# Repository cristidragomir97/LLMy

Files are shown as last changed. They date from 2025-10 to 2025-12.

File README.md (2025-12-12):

# LLMy (leh·mee)
<p>
  
  
  
</p>

<p align="center">
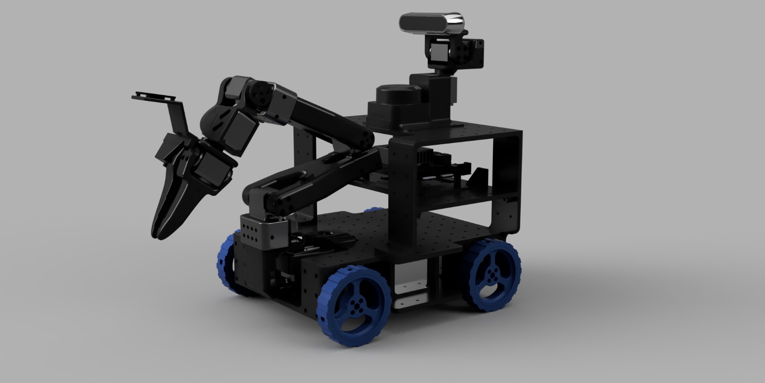
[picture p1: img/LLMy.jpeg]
LLMy Robot
  
</p>

**LLMy** is a fully 3D-printed mobile manipulator designed for **AI experimentation**, **research**, and **education**. Building upon [LeRobot](https://github.com/huggingface/lerobot) and [LeKiwi](https://github.com/SIGRobotics-UIUC), it introduces hardware improvements and comprehensive ROS2 integration.

* 🔧 **Fully 3D Printable** - ORP Grid-based modular design with complete CAD files
* 🤖 **ROS2 Native** - Complete ros2_control integration with MoveIt2 & Nav2 support
* 🎮 **Simulation Ready** - Digital-twin Gazebo simulation with virtual sensors and controllers
* 📷 **RGB-D Vision** - Depth sensing gives you the distance and physical parameters of the objects you detect using neural nets.
* ⚡ **145W Power** - 4-5 hours runtime with USB-C charging
* 💰 **Affordable** - Starting at ~$280 for the base platform

---

## ⚙️ Hardware
The LLMy platform combines a **4-wheel skid-steer base** for robust differential drive mobility with a **6-DOF SO-ARM100 robotic arm** for manipulation tasks. A **pan-tilt elevated camera mount** provides flexible perception capabilities, allowing the robot to survey its environment while performing manipulation operations.

LLMy is designed to be easy to assamble, easy to get started with and easy to expand. 

### Actuators

**12x Feetech STS3215 Servos (12V, 30KG torque):**
- 4x Base wheels (skid-steer drive)
- 6x Arm joints (SO-ARM100)
- 2x Camera head (pan & tilt)

**Control Options:**
- [FE-URT-1](https://www.feetechrc.com/FE-URT1-C001.html)
- [Waveshare Serial Bus Servo Driver](https://www.waveshare.com/bus-servo-adapter-a.htm)

### Power System

- **145W USB-C power bank** with USB-PD trigger modules
- **Hot-swappable charging** - operate while charging
- **4-5 hour runtime** on single charge
- **Nearly solderless** - simplified assembly

### Sensors & Perception

- **RGB-D Camera** - RealSense D435i, ZED 2i, or Orbbec Gemini 2
- **IMU (ICM-20948)** - 9-axis sensor for odometry and SLAM
- **LiDAR (Optional)** - RPLidar C1
- **Wrist Camera** - 640x480 USB camera for manipulation tasks
- **Universal 1/4" mount** - Compatible with various camera systems

### Mechanical Design
- **[ORP Grid-based structure](https://openroboticplatform.com/designrules)** - Modular, expandable design
- **3D printable STL files** - Available in [`/parts`](/parts/) directory
- **Fusion 360 source** - Editable CAD files for customization
- **Expansion ready** - 20x20mm Grid layout supports additional sensors and actuators

### System Diagram

```mermaid
graph TB

    subgraph PowerDelivery["Power Delivery"]
      Battery["145W USB-C Power Bank"]
      Battery --> USBPD1["USB-PD Trigger 1<br/>12V"]
      Battery --> USBPD2["USB-PD Trigger 2<br/>12V"]
    end

    USBPD1 --> SBC["Raspberry Pi 5 / Jetson Orin Nano"]
    USBPD2 --> MotorDriver["Serial Motor Controller<br/>FE-URT-1 / Waveshare"]

    subgraph Actuators["Actuators"]
      MotorDriver -->|Daisy Chain| M1["Servo Motors x11<br/>STS3215"]
    end

    MotorDriver <-->|UART| SBC

    subgraph Sensors["Sensors"]
      IMU["IMU<br/>ICM-20948"]
      Camera["Head Camera<br/>RGB-D"]
      Wrist["Wrist Camera<br/>640x480 USB"]
      LiDAR["LiDAR<br/>RPLidar C1"]
    end

    IMU <-->|I2C| SBC
    Camera -->|USB| SBC
    Wrist -->|USB| SBC
    LiDAR -.->|USB| SBC

```

### Pricing
**📋 [Complete BOM & Sourcing Guide](docs/bom.md)**
| Configuration | US Price | EU Price | What's Included |
|---|---|---|---|
| **Base Platform** | **$264** | **€247** | Servos, controller, IMU, battery |
| **+ RGB-D Camera** | **$498-763** | **€477-696** | + Orbbec Gemini 2/ZED 2i |
| **+ LIDAR** | **$587-852** | **€556-775** | + RPLidar C1/YDLidar options |

---

## 🚀 Quick Start

### 🎮 Simulation (Fastest Way to Try LLMy!)

Get the robot running in Gazebo simulation in just a few commands:

```bash
# Clone and build the workspace
git clone github.com/cristidragomir97/llmy llmy_ws
cd llmy_ws/ros
colcon build
source install/setup.bash

# Launch Gazebo simulation with controllers
ros2 launch llmy_gazebo sim.launch.py
```

The robot will spawn in Gazebo with all controllers active. 

In a new terminal - start Xbox controller teleoperation

```bash
ros2 launch llmy_teleop_xbox teleop_xbox.launch.py
```
**🎮 Xbox Controller Mapping:**
- **🏎️ Base Movement:** Right stick (forward/back + rotate)
- **🦾 Arm Control:**
  - **Joint 1:** RB button (+) / LB button (-)
  - **Joint 2:** RT trigger (+) / LT trigger (-)
  - **Joint 3:** Y button (+) / A button (-)
  - **Joint 4:** B button (+) / X button (-)
  - **Joint 5:** Start button (+) / Back button (-)
  - **Joint 6:** Right stick click (+) / Left stick click (-)
- **📷 Camera Control:**
  - **Pan:** D-pad up/down
  - **Tilt:** D-pad left/right

For detailed setup instructions, hardware configuration, and troubleshooting, see:

**📖 [Getting Started Guide](docs/getting-started.md)** - Complete installation and setup instructions for both simulation and hardware

---

## 🏗️ Architecture

LLMy follows a modular ROS2 architecture that separates concerns between simulation, hardware interfaces, control, and user interaction. 

- **Hardware Abstraction**: The `ros2_control` framework provides a clean interface between high-level controllers (MoveIt2, Nav2) and low-level hardware, allowing the same code to run in both simulation and on real hardware.

- **Modular Sensors**: Each sensor system (cameras, IMU, LIDAR) is encapsulated in its own ROS2 package, publishing standardized messages that any application can consume. This makes it easy to swap sensors or add new ones without modifying application code.

- **Layered Control**: The control stack is separated into layers - from the servo manager handling individual motor commands, through the ros2_control plugin managing the hardware interface, up to high-level motion planning with MoveIt2 and navigation with Nav2.

- **Simulation-First Development**: Gazebo integration allows safe development and testing before deploying to hardware. The same launch files and controllers work in both environments, reducing the simulation-to-reality gap.

```mermaid
graph TB

    LLMyDescription[📦 LLMy_Description]
    API[📡 ROS2]
    Apps[🤖 AI/ML Applications]

    subgraph "Sensors"
        WristCamera[📷 Wrist Camera<br/>UVC 32x32 RGB]
        HeadCamera[📷 Head Camera<br/>RealSense RGB-D]
        IMU[📐 IMU Sensor<br/>ICM20948]
        LIDAR[📏 LIDAR ]
         CameraNode[📦 LLMy_Camera]
        ImuNode[📦 LLMy_IMU]
        LidarNode[📦 rplidar]
    end

    subgraph "Control Layer"
        Control[🎛️ ros2_control Framework]
        LLMyControl[📦 LLMy_Control]
        LLMyControlPlugin[📦 LLMy_ControlPlugin]
    end
    
    subgraph "Actuators"
        LLMyServoManager[📦 LLMy_ServoManager]
        Base[<strong>Skid-Steer Base</strong><br/>4x ST3215 Servos]
        Arm[6-DOF Arm<br/>6x ST3215 Servos]
        Head[Pan & Tilt System<br/>2x ST3215 Servos]
    end

    %% Top to bottom flow
    LLMyDescription --> API

    LIDAR --> LidarNode
    WristCamera --> CameraNode
    HeadCamera --> CameraNode
    IMU --> ImuNode

    LidarNode --> API
    CameraNode --> API
    ImuNode --> API

    API <--> Apps
    API --> Control

    LLMyControl --> Control
    Control --> LLMyControlPlugin
    LLMyControlPlugin --> LLMyServoManager

    LLMyServoManager --> Base
    LLMyServoManager --> Arm
    LLMyServoManager --> Head
    
```

--- 

### 📦 ROS Packages

**Core Packages:**
- [**llmy_description**](ros/src/llmy_description/) - Robot URDF model with accurate kinematics and collision meshes
- [**llmy_control_plugin**](ros/src/llmy_control_plugin) - ros2_control hardware bridge enabling MoveIt2/Nav2 integration
- [**llmy_control**]() - Controller parameters and ros2_control configurations
- [**llmy_servo_manager**]() - Low-level motor control with real-time telemetry
- [**llmy_teleop_xbox**]() - Xbox controller interface for manual operation

**Sensor & Vision:**
- [**llmy_camera**]() - RGB-D camera integration with depth-to-laser conversion
- [**llmy_imu**]() - IMU sensor fusion for orientation and navigation

**Simulation Packages**
- **llmy_gazebo** - Configurations and launch files for the Gazebo Classic

**📋 [Detailed Package Documentation](docs/packages.md)**

--- 
## 🙏 Credits & Acknowledgments
This project stands on the shoulders of incredible open-source work:

- **[LeRobot Team](https://github.com/huggingface/lerobot)** - For pioneering accessible robotics and AI integration
- **[SIGRobotics-UIUC](https://github.com/SIGRobotics-UIUC)** - For their foundational work on LeKiwi
- **[Pavan Vishwanath](https://github.com/Pavankv92)** - ROS2 package development for [LeRobot SO-ARM101](https://github.com/Pavankv92/lerobot_ws)
- **[Mateus Menezes](https://github.com/mateusmenezes95)** - [Omnidirectional controllers](https://github.com/mateusmenezes95/omnidirectional_controllers) and [AxeBot](https://github.com/mateusmenezes95/axebot) simulation expertise
- **[Gaotian Wang](https://github.com/Vector-Wangel/XLeRobot)** - For his amazing work on XLeRobot. Also for being kind enough to publish the STEP files for his robot upon request, files that were used to create the camera tower for LLMy. 

---
<div align="center">

<strong>⭐ Star this repo if LLMy helped you build something awesome! ⭐</strong>
</div>

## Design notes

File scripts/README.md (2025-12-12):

# LLMy Setup Scripts

Utility scripts for configuring and calibrating your LLMy robot.

## Scripts Overview

### 1. `set_servo_id.py` - Servo ID Configuration

Interactive tool for setting FEETECH STS3215 servo IDs one by one.

**Usage:**

```bash
# List all servos on the bus with telemetry
python3 set_servo_id.py --list

# Interactive mode - configure servos one by one
python3 set_servo_id.py

# Direct ID change
python3 set_servo_id.py --old-id 1 --new-id 5

# Custom serial port
python3 set_servo_id.py --port /dev/ttyACM0 --list
```

**LLMy ID Assignments:**
- Base (locomotion): IDs **1, 2, 3**
- Arm (manipulator): IDs **4, 5, 6, 7, 8, 9**
- Head (pan & tilt): IDs **10, 11**

**Workflow:**
1. Connect servos **one at a time** to avoid ID conflicts
2. Run interactive mode: `python3 set_servo_id.py`
3. For each servo:
   - Connect it to the bus
   - Script detects current ID
   - Enter desired new ID
   - Disconnect and connect next servo
4. Final verification scan shows all configured servos

---

### 2. `calibrate_arm.py` - Arm Calibration

Calibrates arm joint zero positions and movement limits.

**Usage:**

```bash
# Basic calibration (will prompt for save)
python3 calibrate_arm.py

# Auto-save to config file
python3 calibrate_arm.py --config ~/llmy_ws/ros/src/llmy_servo_manager/config/servo_manager.yaml

# Custom serial port
python3 calibrate_arm.py --port /dev/ttyUSB0
```

**⚠️ IMPORTANT:** Stop all ROS2 nodes before running calibration!

```bash
# Kill any running servo manager nodes
pkill -f servo_manager
```

**Calibration Process:**

1. **Zero Position Setup:**
   - Position arm fully erect (vertical)
   - Close gripper completely
   - Center wrist rotation
   - Script records zero positions

2. **Joint Limit Calibration:**
   - For each of 6 arm joints:
     - Move joint to minimum position → record
     - Move joint to maximum position → record
   - Script validates and saves limits

3. **Verification:**
   - Arm returns to zero position
   - Summary table shows all calibration data
   - Option to save to YAML config

**Output Example:**
```
┌─────────────────────────┬──────┬──────────┬─────────┬─────────┐
│ Joint                   │  ID  │ Zero Pos │ Min Pos │ Max Pos │
├─────────────────────────┼──────┼──────────┼─────────┼─────────┤
│ Joint 1 (Base Rotation) │   4  │  2048    │   512   │  3584   │
│ Joint 2 (Shoulder)      │   5  │  2048    │   768   │  3328   │
...
```

**What Gets Saved:**

The calibration tool updates `servo_manager.yaml` with:
- `arm_zero_positions`: Reference position for each joint (6 values)
- `arm_min_limits`: Minimum safe position in ticks (6 values)
- `arm_max_limits`: Maximum safe position in ticks (6 values)

These limits are automatically enforced by the servo manager to prevent damage.

---

## Prerequisites

### Hardware Setup
- Robot powered on (12V to servos)
- Serial connection established (USB or UART)
- Correct serial port identified

### Software Requirements
```bash
# Install st3215 Python library
pip install st3215

# Install PyYAML for config management
pip install pyyaml
```

### Permissions
```bash
# Add your user to dialout group for serial access
sudo usermod -a -G dialout $USER
# Log out and back in for changes to take effect
```

---

## Common Serial Ports

| Platform | Port | Description |
|---|---|---|
| Raspberry Pi | `/dev/ttyUSB0` | USB adapter |
| Jetson Nano/Orin | `/dev/ttyTHS1` | Hardware UART |
| Generic Linux | `/dev/ttyACM0` | USB CDC adapter |
| Waveshare adapter | `/dev/ttyUSB0` | FT232 USB-Serial |

**Find your port:**
```bash
# List all serial devices
ls /dev/tty{USB,ACM,THS}* 2>/dev/null

# Monitor kernel messages when plugging in
dmesg | tail
```

---

## Workflow: Full Robot Setup

**Complete setup from scratch:**

```bash
# 1. Set all servo IDs (connect one at a time)
cd ~/llmy_ws/scripts
python3 set_servo_id.py

# 2. Verify all servos are detected
python3 set_servo_id.py --list

# 3. Calibrate arm joints
python3 calibrate_arm.py --config ../ros/src/llmy_servo_manager/config/servo_manager.yaml

# 4. Build and launch ROS workspace
cd ~/llmy_ws/ros
colcon build
source install/setup.bash
ros2 launch llmy_bringup bringup_robot.launch.py
```

---

## Troubleshooting

### Script can't connect to servos
```bash
# Check port exists
ls -l /dev/ttyUSB0

# Check permissions
groups  # Should show 'dialout'

# Try different baud rates
python3 set_servo_id.py --baud 115200
```

### Servo not responding during calibration
- Ensure 12V power supply is connected
- Check servo cables are properly seated
- Verify servo ID matches expected value
- Try power cycling the servo

### Calibration data not saving
- Verify config file path is correct
- Check file permissions (must be writable)
- Review backup file (.backup) for changes
- Manually inspect YAML syntax

### ROS node conflicts
```bash
# Kill all servo-related processes
pkill -f servo_manager
pkill -f llmy

# Verify no nodes running
ros2 node list
```

---

## Advanced Usage

### Batch ID Configuration
```bash
# Script for setting multiple servos
for id in {1..11}; do
  echo "Connect servo for ID $id and press enter..."
  read
  python3 set_servo_id.py --old-id 1 --new-id $id
done
```

### Custom Calibration Workflow
```python
# Manual calibration via Python API
from st3215 import ST3215

servo = ST3215('/dev/ttyUSB0')
pos = servo.ReadPosition(4)  # Read joint 1 position
print(f"Current position: {pos} ticks")
```

### Verify Limits Are Enforced
```bash
# After calibration, test limit enforcement
ros2 topic pub /motor_manager/arm_cmd std_msgs/msg/Float64MultiArray "data: [10.0, 0, 0, 0, 0, 0]"
# Joint should clamp to max limit, not attempt invalid position
```

---

## Support

For issues or questions:
- GitHub Issues: https://github.com/cristidragomir97/llmy/issues
- Documentation: [docs/getting-started.md](../docs/getting-started.md)

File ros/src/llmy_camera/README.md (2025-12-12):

# llmy_camera

Camera integration package for the LLMy robot, providing both a head-mounted RealSense RGB-D camera and a wrist-mounted USB camera with compressed image transport and laser scan conversion capabilities.

## Overview

The llmy_camera package manages two camera systems:
- **Head Camera**: Intel RealSense RGB-D camera (D435i, D455, etc.) mounted on the pan/tilt head
- **Wrist Camera**: USB camera (640x480) mounted on the end-effector for close-up manipulation tasks

## Launch Files

### `camera.launch.py`

Main launch file that brings up both camera systems with full feature set:

**Components:**
- RealSense RGB-D camera (head_camera namespace)
- USB wrist camera (wrist_camera namespace)
- Compressed image transport for both cameras
- Depth-to-laser-scan conversion for navigation

```bash
# Launch both cameras with all features
ros2 launch llmy_camera camera.launch.py

# Launch without wrist camera
ros2 launch llmy_camera camera.launch.py enable_wrist_camera:=false

# Launch without laser scan conversion
ros2 launch llmy_camera camera.launch.py enable_laser_scan:=false

# Disable compressed transport
ros2 launch llmy_camera camera.launch.py enable_compressed:=false
```

### `realsense_only.launch.py`

Minimal launch file for RealSense camera only (no wrist camera, no laser scan, no compression):

```bash
# Launch only RealSense camera
ros2 launch llmy_camera realsense_only.launch.py

# Specify device type
ros2 launch llmy_camera realsense_only.launch.py device_type:=d435i
```

## Launch Arguments

### `camera.launch.py` Arguments

| Argument | Default | Description |
|---|---|---|
| `camera_name` | `head_camera` | RealSense camera name |
| `device_type` | `` | RealSense device type (auto-detect if empty) |
| `enable_wrist_camera` | `true` | Enable USB wrist camera |
| `wrist_camera_device` | `/dev/video0` | Video device path for wrist camera |
| `enable_compressed` | `true` | Enable compressed image transport |
| `enable_laser_scan` | `true` | Enable depth to laser scan conversion |
| `laser_scan_min_height` | `-0.5` | Minimum height for laser scan slice (m) |
| `laser_scan_max_height` | `0.5` | Maximum height for laser scan slice (m) |
| `laser_scan_angle_min` | `-1.57` | Minimum scan angle (-90°) |
| `laser_scan_angle_max` | `1.57` | Maximum scan angle (+90°) |
| `laser_scan_angle_increment` | `0.005` | Angular resolution |
| `laser_scan_range_min` | `0.2` | Minimum range (m) |
| `laser_scan_range_max` | `10.0` | Maximum range (m) |

### `realsense_only.launch.py` Arguments

| Argument | Default | Description |
|---|---|---|
| `camera_name` | `camera` | RealSense camera name |
| `device_type` | `d435i` | RealSense device type |

## Topics Published

### Head Camera (RealSense)

**Color Stream:**
- `/head_camera/head_camera/color/image_raw` - Raw color image (640x480@30Hz)
- `/head_camera/head_camera/color/image_compressed` - Compressed color image (JPEG)
- `/head_camera/head_camera/color/camera_info` - Camera calibration

**Depth Stream:**
- `/head_camera/head_camera/depth/image_rect_raw` - Rectified depth image
- `/head_camera/head_camera/depth/camera_info` - Depth camera calibration

**Laser Scan:**
- `/scan` - 2D laser scan converted from depth (for navigation)

### Wrist Camera (USB)

- `/wrist_camera/image_raw` - Raw wrist camera image (640x480@30Hz)
- `/wrist_camera/image_compressed` - Compressed wrist image (JPEG)
- `/wrist_camera/camera_info` - Camera calibration

## Supported Hardware

### RealSense Cameras
- Intel RealSense D435i (recommended)
- Intel RealSense D455
- Intel RealSense L515
- Other RealSense RGB-D cameras

### Wrist Camera
- Any UVC-compatible USB camera
- Default: 640x480@30fps, MJPEG format

## Usage Examples

### View Camera Streams

```bash
# View head camera color stream
ros2 run rqt_image_view rqt_image_view /head_camera/head_camera/color/image_raw

# View head camera depth
ros2 run rqt_image_view rqt_image_view /head_camera/head_camera/depth/image_rect_raw

# View wrist camera
ros2 run rqt_image_view rqt_image_view /wrist_camera/image_raw

# View compressed images (bandwidth efficient)
ros2 run rqt_image_view rqt_image_view /head_camera/head_camera/color/image_compressed/compressed
ros2 run rqt_image_view rqt_image_view /wrist_camera/image_compressed/compressed
```

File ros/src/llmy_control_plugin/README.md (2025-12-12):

# llmy_control_plugin

A `ros2_control` **SystemInterface** hardware plugin that bridges ros2_control to the LLMy servo manager via ROS2 topics.

## Purpose

This plugin implements the hardware abstraction layer for ros2_control, allowing standard controllers to work with LLMy hardware. It uses a topic-based interface rather than direct serial communication, which decouples the control stack from hardware details.

## Topic Interface

### Published (Commands to Hardware)

- **`/motor_manager/base_cmd`** - `std_msgs/Float64MultiArray`
  - `[back_motor_rotation, left_motor_rotation, right_motor_rotation]` (rad/s)
  - QoS: Best-effort, depth 1

- **`/motor_manager/arm_cmd`** - `std_msgs/Float64MultiArray`
  - `[joint_1, joint_2, joint_3, joint_4, joint_5, joint_6]` (radians)
  - QoS: Best-effort, depth 1

- **`/motor_manager/head_cmd`** - `std_msgs/Float64MultiArray`
  - `[camera_pan, camera_tilt]` (radians)
  - QoS: Best-effort, depth 1

### Subscribed (Feedback from Hardware)

- **`/motor_manager/joint_states`** - `sensor_msgs/JointState`
  - All joint positions and velocities
  - QoS: Reliable, depth 5

## Hardware Interfaces Exported

The plugin exports these command and state interfaces to ros2_control:

**Base (velocity interfaces):**
- `back_motor_rotation/velocity`
- `left_motor_rotation/velocity`
- `right_motor_rotation/velocity`

**Arm (position interfaces):**
- `1/position`, `2/position`, `3/position`, `4/position`, `5/position`, `6/position`

**Head (position interfaces):**
- `camera_pan/position`, `camera_tilt/position`

## Configuration

### Hardware Interface Config

Configuration is in `llmy_control/config/ros2_control_bridge.yaml`:

```yaml
hardware_interface:
  plugin: "llmy_control_plugin/ROS2ControlBridge"
  base_joints: [back_motor_rotation, left_motor_rotation, right_motor_rotation]
  arm_joints: ["1", "2", "3", "4", "5", "6"]
  head_joints: [camera_pan, camera_tilt]
```

## Usage

This plugin is loaded automatically by `llmy_control/control_stack.launch.py`. You don't typically interact with it directly.

### Normal Usage

```bash
# Launch complete system (includes this plugin)
ros2 launch llmy_control control_stack.launch.py
```

### Standalone Testing

```bash
# 1. Start servo manager
ros2 launch llmy_servo_manager servo_manager.launch.py

# 2. Launch plugin (requires robot_description)
ros2 launch llmy_control_plugin bringup.launch.py
```

## Implementation Notes

### Lifecycle

1. **`on_init()`** - Read configuration, register joint interfaces
2. **`on_configure()`** - Create publishers and subscribers
3. **`on_activate()`** - Ready for control
4. **`read()`** - Update state interfaces from `/motor_manager/joint_states` (called at update rate)
5. **`write()`** - Publish commands from command interfaces (called at update rate)

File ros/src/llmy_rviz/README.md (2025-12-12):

# llmy_rviz

RViz2 configuration and visualization package for the LLMy robot.

## Features

This package provides comprehensive visualization for:

### Robot Visualization
- **Robot Model**: Full 3D visualization of the LLMy robot from URDF
- **TF Tree**: Transform frame visualization showing all coordinate frames

### Sensor Data
- **LaserScan**: 2D lidar visualization (`/scan` topic)
- **Head Camera RGB**: Color camera feed from head camera
- **Head Camera Depth**: Depth camera visualization (disabled by default)
- **Wrist Camera**: RGB camera on robot wrist (disabled by default)
- **Depth PointCloud**: 3D point cloud from depth camera (disabled by default)

### SLAM & Navigation
- **Map**: Occupancy grid map from SLAM (`/map` topic)
- **Global Plan**: Planned path from navigation (`/plan` topic)
- **Local Plan**: Local planner trajectory (`/local_plan` topic)
- **Local Costmap**: Real-time obstacle avoidance costmap
- **Global Costmap**: Global planning costmap

### Tools
- **2D Pose Estimate**: Set initial robot pose for localization
- **2D Nav Goal**: Send navigation goals to the robot
- **Measure**: Measure distances in the environment
- **Publish Point**: Click to publish 3D points

## Usage

### Launch RViz with default configuration:
```bash
ros2 launch llmy_rviz rviz.launch.py
```

### Launch with custom config:
```bash
ros2 launch llmy_rviz rviz.launch.py rviz_config:=/path/to/config.rviz
```

### Launch with hardware (no sim time):
```bash
ros2 launch llmy_rviz rviz.launch.py use_sim_time:=false
```

## Configuration

The main RViz configuration file is located at:
```
rviz/llmy.rviz
```

You can customize this file or create new configurations and save them in the `rviz/` directory.

## Topics Subscribed

- `/robot_description` - Robot model URDF
- `/scan` - LaserScan data
- `/map` - Occupancy grid map
- `/plan` - Global navigation plan
- `/local_plan` - Local navigation plan
- `/local_costmap/costmap` - Local costmap
- `/global_costmap/costmap` - Global costmap
- `/head_camera/rgb` - Head camera RGB image
- `/head_camera/depth` - Head camera depth image
- `/head_camera/depth/points` - Depth point cloud
- `/wrist_camera/rgb` - Wrist camera RGB image

## Dependencies

- rviz2
- rviz_common
- rviz_default_plugins
- robot_state_publisher
- llmy_description

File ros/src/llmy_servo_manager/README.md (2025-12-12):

# LLMy Servo Manager

Servo control system for the LLMy Robot.

- **Multi-Motor Support**: Controls locomotion, arm, and head motor groups independently
- **Real-time Telemetry**: Publishes motor states at configurable rates
- **Robust Error Handling**: Comprehensive connectivity testing and graceful error recovery

## Architecture

### Core Modules

- **`servo_manager_node.py`**: Main ROS2 node orchestrating all components
- **`config.py`**: Configuration management and parameter validation
- **`motor_manager.py`**: Low-level motor communication and control
- **`brake_system.py`**: Safe motor braking with multiple strategies
- **`command_handlers.py`**: ROS message processing and motor command conversion
- **`telemetry.py`**: Motor state publishing and monitoring

## Configuration

The servo manager is configured via ROS2 parameters, typically loaded from `config/servo_manager.yaml`:

### Communication Parameters
```yaml
port: "/dev/ttyTHS1"          # Serial port for motor communication
baud: 1000000                 # Baud rate (default: 1 Mbps)
ticks_per_rev: 4096           # Encoder ticks per revolution
telemetry_rate: 30.0          # Telemetry publishing rate (Hz)
```

### Motor Group Configuration
```yaml
# Enable/disable motor groups
loc_enable: true              # Locomotion motors
arm_enable: true              # Arm motors  
head_enable: true             # Head motors

# Motor IDs for each group
loc_ids: [1, 2, 3]           # Locomotion motor IDs
arm_ids: [4, 5, 6, 7, 8, 9]  # Arm motor IDs
head_ids: [10, 11]           # Head motor IDs

# Acceleration settings (per motor)
loc_accel: [15, 15, 15]
arm_accel: [20, 20, 15, 15, 25, 25]
head_accel: [15, 15]

# Speed scaling factors (0.0 to 2.0)
loc_speed_scale: 0.2         # Conservative for locomotion
arm_speed_scale: 1.0         # Normal for arm
head_speed_scale: 1.0        # Normal for head
```

### Braking System Configuration
```yaml
# Braking method: "torque_disable", "velocity_ramp", "position_brake"
brake_method: "torque_disable"  # Gentlest method (recommended)
velocity_ramp_time: 0.5         # Ramp down time for velocity_ramp (seconds)
brake_acceleration: 100         # Acceleration for position_brake method
```

## ROS2 Interface

### Subscribed Topics

- **`/motor_manager/base_cmd`** (`Float64MultiArray`)
  - Velocity commands for locomotion motors (rad/s)
  - Array size must match number of locomotion motors

- **`/motor_manager/arm_cmd`** (`Float64MultiArray`)  
  - Position commands for arm motors (radians)
  - Array size must match number of arm motors

- **`/motor_manager/head_cmd`** (`Float64MultiArray`)
  - Position commands for head motors (radians)
  - Array size must match number of head motors

### Published Topics

- **`/motor_manager/joint_states`** (`JointState`)
  - Current motor positions and velocities
  - Published at configured telemetry rate
  - Contains all enabled motors with naming: `motor_{id}`

## Usage

### Basic Launch
```bash
ros2 launch llmy_servo_manager servo_manager.launch.py
```

### With Custom Configuration
```bash
ros2 launch llmy_servo_manager servo_manager.launch.py \
    config_file:=custom_servo_config.yaml
```

## Monitoring and Diagnostics

### View Motor States
```bash
ros2 topic echo /motor_manager/joint_states
```

### Check Node Status
```bash
ros2 node info /servo_manager_node
```

### Monitor Motor Connectivity
The node automatically tests motor connectivity on startup and logs detailed status information.

## Troubleshooting

### Common Issues

1. **Serial Port Permission Denied**
   ```bash
   sudo usermod -a -G dialout $USER
   # Then logout and login again
   ```

2. **Motors Not Responding**
   - Check physical connections
   - Verify motor IDs in configuration
   - Ensure proper power supply
   - Check serial port settings

### Debug Mode
Enable debug logging to see detailed brake operations:
```bash
ros2 run llmy_servo_manager servo_manager_node --ros-args --log-level DEBUG
```

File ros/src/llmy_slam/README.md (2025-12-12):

# llmy_slam

SLAM (Simultaneous Localization and Mapping) integration for the LLMy robot using [slam_toolbox](https://github.com/SteveMacenski/slam_toolbox).

This package provides custom launch files and configurations specifically tailored for the LLMy robot's hardware setup.

## Overview

This package wraps slam_toolbox with LLMy-specific configurations for:
- **Sensor input**: RPLidar on `/scan` topic
- **Odometry**: Omnidirectional controller publishing `/omnidirectional_controller/odom` and TF `odom` → `base_link`
- **Base frame**: `base_link`
- **Map frame**: `map`

## Prerequisites

1. **Install slam_toolbox**:
   ```bash
   sudo apt install ros-${ROS_DISTRO}-slam-toolbox
   ```

2. **Ensure RPLidar is publishing** on `/scan` topic:
   - Enable RPLidar in your bringup configuration
   - Or use depth-to-laserscan from the RealSense camera

3. **Verify odometry is being published**:
   ```bash
   ros2 topic echo /omnidirectional_controller/odom
   ```

   Note: slam_toolbox uses TF transforms (`odom` → `base_link`) rather than subscribing to the odometry topic directly.

## Usage

### 1. Mapping Mode (Creating a Map)

Launch slam_toolbox in online asynchronous mapping mode:

```bash
ros2 launch llmy_slam online_async_launch.py
```

**Options:**
- `use_sim_time:=true` - Use simulation time (for Gazebo)
- `params_file:=/path/to/custom/params.yaml` - Use custom parameters

**While mapping:**
- Drive the robot around using teleop or xbox controller
- The map will be built in real-time
- You can view the map in RViz by adding the `/map` topic

**To save the map:**

Use the slam_toolbox service:
```bash
ros2 service call /slam_toolbox/save_map slam_toolbox/srv/SaveMap "{name: {data: '/path/to/your/map_name'}}"
```

This will create two files:
- `map_name.posegraph` - SLAM graph data
- `map_name.data` - Serialized map data

### 2. Localization Mode (Using a Pre-built Map)

Once you have a saved map, you can use it for localization only:

1. **Update the map path** in `config/mapper_params_localization.yaml`:
   ```yaml
   map_file_name: /path/to/your/saved/map_name
   ```

2. **Launch localization**:
   ```bash
   ros2 launch llmy_slam localization_launch.py
   ```

In this mode, the robot will localize itself within the existing map without modifying it.

### 3. Lifelong Mode (Dynamic Mode Switching) ⭐ **Recommended**

Lifelong mode is the most flexible approach, allowing you to **dynamically switch between mapping and localization** using ROS services without restarting the node.

**Launch lifelong mode:**
```bash
ros2 launch llmy_slam lifelong_launch.py
```

**Options:**
- `use_sim_time:=true` - Use simulation time (for Gazebo)
- `params_file:=/path/to/custom/params.yaml` - Use custom parameters

#### Dynamic Mode Switching with Services

Once running, you can control the SLAM behavior using these services:

**1. Pause Mapping (Switch to Localization Mode):**
```bash
ros2 service call /slam_toolbox/pause_new_measurements std_srvs/srv/SetBool "{data: true}"
```

**2. Resume Mapping:**
```bash
ros2 service call /slam_toolbox/pause_new_measurements std_srvs/srv/SetBool "{data: false}"
```

**3. Save the Current Map (while running):**
```bash
ros2 service call /slam_toolbox/serialize_map slam_toolbox/srv/SerializePoseGraph "{filename: '/path/to/map_name'}"
```

**4. Load an Existing Map (while running):**
```bash
ros2 service call /slam_toolbox/deserialize_map slam_toolbox/srv/DeserializePoseGraph "{filename: '/path/to/map_name', match_type: 2}"
```
- `match_type: 1` - Start at the origin of the loaded map
- `match_type: 2` - Start at the current position (relocalize in the map)

**5. Clear the Current Queue:**
```bash
ros2 service call /slam_toolbox/clear_queue std_srvs/srv/Empty
```

#### Example Workflow with Lifelong Mode

```bash
# 1. Launch lifelong SLAM
ros2 launch llmy_slam lifelong_launch.py

# 2. Drive around and build a map
# ... (use teleop/xbox controller)

# 3. Save the map
ros2 service call /slam_toolbox/serialize_map slam_toolbox/srv/SerializePoseGraph \
  "{filename: '/home/user/maps/office_map'}"

# 4. Switch to localization mode (pause mapping)
ros2 service call /slam_toolbox/pause_new_measurements std_srvs/srv/SetBool "{data: true}"

# 5. Later, resume mapping to update the map
ros2 service call /slam_toolbox/pause_new_measurements std_srvs/srv/SetBool "{data: false}"

# 6. Or load a different map entirely
ros2 service call /slam_toolbox/deserialize_map slam_toolbox/srv/DeserializePoseGraph \
  "{filename: '/home/user/maps/warehouse_map', match_type: 2}"
```

#### Advantages of Lifelong Mode

- **No restarts needed** - Switch modes on the fly
- **Flexible workflows** - Map, localize, then continue mapping
- **Multi-session mapping** - Save and continue mapping across multiple sessions
- **Hot-swapping maps** - Load different maps without stopping the node

## Configuration Files

### `config/mapper_params_lifelong.yaml`
Configuration for lifelong mode with dynamic behavior:
- Supports both mapping and localization
- Can load existing maps and continue mapping
- Full service interface for dynamic control
- Recommended for production deployments

### `config/mapper_params_online_async.yaml`
Configuration for online mapping mode. Key parameters:
- `scan_topic: /scan` - Laser scan input
- `odom_frame: odom` - Odometry frame
- `base_frame: base_link` - Robot base frame
- `map_frame: map` - Map frame
- `max_laser_range: 12.0` - RPLidar typical max range
- `resolution: 0.05` - Map resolution (5cm per pixel)
- `minimum_travel_distance: 0.2` - Minimum movement before updating (meters)

### `config/mapper_params_localization.yaml`
Configuration for localization mode. Similar to mapping mode but with:
- `mode: localization` - Only localizes, doesn't update map
- `map_file_name: /path/to/map` - Path to pre-built map

## RViz Visualization

To visualize SLAM in RViz:

1. Launch RViz:
   ```bash
   rviz2
   ```

2. Add the following displays:
   - **TF** - To see coordinate frames
   - **Map** - Topic: `/map`
   - **LaserScan** - Topic: `/scan`
   - **RobotModel** - Uses the URDF description

3. Set **Fixed Frame** to `map`

## Integration with LLMy Bringup

To automatically start SLAM with your robot, you can include this launch file in `llmy_bringup`:

```python
from launch.actions import IncludeLaunchArgument, IncludeLaunchDescription
from launch.launch_description_sources import PythonLaunchDescriptionSource
from launch.substitutions import LaunchConfiguration

# Option 1: Lifelong mode (recommended for flexibility)
slam_launch = IncludeLaunchDescription(
    PythonLaunchDescriptionSource(
        PathJoinSubstitution([
            FindPackageShare('llmy_slam'),
            'launch',
            'lifelong_launch.py'
        ])
    )
)

# Option 2: Online mapping mode (simpler, mapping only)
# slam_launch = IncludeLaunchDescription(
#     PythonLaunchDescriptionSource(
#         PathJoinSubstitution([
#             FindPackageShare('llmy_slam'),
#             'launch',
#             'online_async_launch.py'
#         ])
#     )
# )
```

## Topics

### Subscribed:
- `/scan` (sensor_msgs/LaserScan) - Laser scan from RPLidar
- `/tf` - Transform tree (requires `odom` → `base_link` transform)
- `/tf_static` - Static transforms

**Note**: slam_toolbox does not subscribe to `/omnidirectional_controller/odom` directly. It uses the TF transform `odom` → `base_link` published by the omnidirectional controller.

### Published:
- `/map` (nav_msgs/OccupancyGrid) - Generated map
- `/tf` - Publishes `map` → `odom` transform

## Services

slam_toolbox provides many useful services:

### Core Services

- `/slam_toolbox/pause_new_measurements` - **Pause/resume mapping** (switch to localization mode)
- `/slam_toolbox/serialize_map` - **Save map to file** (posegraph format)
- `/slam_toolbox/deserialize_map` - **Load map from file** and optionally relocalize
- `/slam_toolbox/save_map` - Save map as standard ROS map format (.pgm + .yaml)
- `/slam_toolbox/clear_queue` - Clear the scan queue

### Additional Services

- `/slam_toolbox/toggle_interactive_mode` - Enable/disable interactive markers in RViz
- `/slam_toolbox/clear` - Clear the current graph (start fresh)
- `/slam_toolbox/dynamic_map` - Get the current map
- `/slam_toolbox/manual_loop_closure` - Manually trigger loop closure

List all available services:
```bash
ros2 service list | grep slam_toolbox
```

Get service details:
```bash
ros2 service type /slam_toolbox/pause_new_measurements
ros2 interface show std_srvs/srv/SetBool
```

### Quick Service Reference

**Save map (posegraph format, can be loaded back):**
```bash
ros2 service call /slam_toolbox/serialize_map slam_toolbox/srv/SerializePoseGraph \
  "{filename: '/home/user/maps/my_map'}"
```

**Save map (standard ROS format, for navigation stack):**
```bash
ros2 service call /slam_toolbox/save_map slam_toolbox/srv/SaveMap \
  "{name: {data: '/home/user/maps/my_map'}}"
```

**Load map and relocalize:**
```bash
ros2 service call /slam_toolbox/deserialize_map slam_toolbox/srv/DeserializePoseGraph \
  "{filename: '/home/user/maps/my_map', match_type: 2}"
```

**Pause mapping (localization only):**
```bash
ros2 service call /slam_toolbox/pause_new_measurements std_srvs/srv/SetBool "{data: true}"
```

**Resume mapping:**
```bash
ros2 service call /slam_toolbox/pause_new_measurements std_srvs/srv/SetBool "{data: false}"
```

### Helper Script

For convenience, a helper script is provided to simplify common operations:

```bash
# After building the package, the script will be available at:
ros2 pkg prefix llmy_slam
# Or use it directly from source:
./ros/src/llmy_slam/scripts/slam_control.sh

# Usage examples:
./scripts/slam_control.sh pause                         # Pause mapping
./scripts/slam_control.sh resume                        # Resume mapping
./scripts/slam_control.sh save /path/to/map            # Save map
./scripts/slam_control.sh save_ros /path/to/map        # Save as ROS format
./scripts/slam_control.sh load /path/to/map            # Load map
./scripts/slam_control.sh list                         # List all services
```

## Troubleshooting

### No map appearing
- Check that `/scan` topic is publishing: `ros2 topic echo /scan`
- Verify TF tree is complete: `ros2 run tf2_tools view_frames`
- Check that odometry is being published: `ros2 topic echo /omnidirectional_controller/odom`
- Verify `odom` → `base_link` TF is published: `ros2 run tf2_ros tf2_echo odom base_link`

### Poor map quality
- Adjust `minimum_travel_distance` and `minimum_travel_heading` parameters
- Increase `loop_closure` parameters for better loop detection
- Ensure your laser scan data is clean and not noisy

### Transform errors
- Verify that `odom` → `base_link` transform is being published by omnidirectional_controller:
  ```bash
  ros2 run tf2_ros tf2_echo odom base_link
  ```
- Check that all sensor frames are properly defined in the URDF
- Use `ros2 run tf2_tools view_frames` to debug TF tree
- Ensure `/omnidirectional_controller/odom` topic is publishing

## Parameters Tuning

Key parameters you might want to adjust based on your environment:

- **For small environments** (< 10m x 10m):
  - Decrease `loop_search_maximum_distance`
  - Increase `minimum_travel_distance`

- **For large environments** (> 50m x 50m):
  - Increase `loop_search_maximum_distance`
  - Decrease `minimum_travel_distance`
  - Increase `stack_size_to_use`

- **For fast-moving robots**:
  - Decrease `minimum_time_interval`
  - Increase `transform_publish_period`

## License

MIT

## References

- [slam_toolbox documentation](https://github.com/SteveMacenski/slam_toolbox)
- [slam_toolbox ROS2 tutorial](https://navigation.ros.org/tutorials/docs/using_slam_toolbox.html)

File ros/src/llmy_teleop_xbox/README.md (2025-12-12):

# llmy_teleop_xbox

Xbox controller teleoperation for LLMy robot, providing intuitive control of the omnidirectional base, 6-DOF robotic arm, and pan-tilt camera head.

## Features

- **Right stick base control** - Forward/backward and rotation
- **Button-based arm control** - All 6 joints controlled via buttons and triggers
- **Button-based arm control** - Joints 3-6 with single press and hold-to-repeat
- **D-pad camera control** - Pan (up/down) and tilt (left/right)
- **Smooth acceleration** - Gradual velocity changes for base movement
- **Deadband filtering** - Prevents controller drift
- **Joint limit enforcement** - Prevents invalid camera positions

## Control Mapping

### 🏎️ Base Movement
- **Right Stick Forward/Back** - Linear movement (forward/backward)
- **Right Stick Left/Right** - Rotation (turn left/right)
- **Left Stick Left/Right** - Lateral movement (strafe left/right)

### 🦾 Arm Control

**Joint 1 (Base Rotation):**
- **RB (Right Bumper)** - Increase joint 1 (+)
- **LB (Left Bumper)** - Decrease joint 1 (-)

**Joint 2 (Shoulder):**
- **RT (Right Trigger)** - Increase joint 2 (+)
- **LT (Left Trigger)** - Decrease joint 2 (-)

**Joint 3 (Elbow):**
- **Y Button** - Increase joint 3 (+)
- **A Button** - Decrease joint 3 (-)

**Joint 4 (Wrist 1):**
- **B Button** - Increase joint 4 (+)
- **X Button** - Decrease joint 4 (-)

**Joint 5 (Wrist 2):**
- **Start Button** - Increase joint 5 (+)
- **Back Button** - Decrease joint 5 (-)

**Joint 6 (Wrist 3):**
- **Right Stick Click** - Increase joint 6 (+)
- **Left Stick Click** - Decrease joint 6 (-)

### 📷 Camera Control

- **D-pad Left** - Tilt down (-)
- **D-pad Right** - Tilt up (+)
- **D-pad Up** - Pan right (+)
- **D-pad Down** - Pan left (-)

**Note:** All buttons support both single press (small increment) and hold-to-repeat (continuous movement).

## Configuration

### Parameters

| Parameter | Default | Description |
|---|---|---|
| `cmd_vel_topic` | `/cmd_vel_xbox` | Base velocity command topic |
| `arm_cmd_topic` | `/arm_controller/commands` | Arm command topic |
| `head_cmd_topic` | `/head_controller/commands` | Head command topic |
| `linear_scale` | `0.2` | Forward/backward speed scaling |
| `angular_scale` | `0.5` | Rotation speed scaling |
| `arm_increment` | `0.1745` (10°) | Standard joint increment |
| `arm_increment_fast` | `0.1396` (8°) | Fast joint increment (joints 1-4) |
| `stick_deadband` | `0.1` | Analog stick deadband threshold |
| `trigger_threshold` | `0.3` | Trigger press threshold |
| `arm_rate` | `30.0` | Arm/head command rate (Hz) |
| `base_rate` | `50.0` | Base command rate (Hz) |
| `acceleration_limit` | `2.0` | Max acceleration for base (m/s²) |

### Joint Limits

Camera head has enforced joint limits:
- **camera_pan**: -3.14 to 3.14 rad (full rotation)
- **camera_tilt**: -1.57 to 0.86 rad (tilt range)

## Usage

### Hardware Setup

1. Connect Xbox controller via USB or wireless adapter
2. Verify controller detection:
```bash
ls /dev/input/js*
ros2 run joy joy_enumerate_devices
```

### Launch Teleoperation

```bash
# Launch with joy node included
ros2 launch llmy_teleop_xbox teleop_xbox.launch.py

# Or launch manually
ros2 run joy joy_node &
ros2 run llmy_teleop_xbox teleop_xbox.py
```

### Custom Parameters

```bash
# Faster base movement
ros2 run llmy_teleop_xbox teleop_xbox.py --ros-args \
  -p linear_scale:=0.4 \
  -p angular_scale:=0.8

# Larger arm increments
ros2 run llmy_teleop_xbox teleop_xbox.py --ros-args \
  -p arm_increment:=0.2618  # 15 degrees
```

### Monitoring

```bash
# Monitor base commands
ros2 topic echo /cmd_vel_xbox

# Monitor arm commands
ros2 topic echo /arm_controller/commands

# Monitor head commands
ros2 topic echo /head_controller/commands

# Check joystick input
ros2 topic echo /joy
```

## Integration

This package publishes to topics that are multiplexed by the main bringup system:

- **Base commands** → `/cmd_vel_xbox` → Multiplexed to `/omnidirectional_controller/cmd_vel_unstamped`
- **Arm commands** → `/arm_controller/commands` → Processed by arm controller
- **Head commands** → `/head_controller/commands` → Processed by head controller

The `twist_mux` in `llmy_bringup` handles command prioritization, with teleop having priority 10 (medium).

## Safety Features

- **Smooth acceleration** - Base velocity changes gradually to prevent jerky motion
- **Deadband filtering** - Ignores small stick movements from drift
- **Joint limits** - Camera joints clamped to safe ranges
- **Rate limiting** - Commands published at controlled frequency
- **Zero velocity on release** - Base stops when stick returns to center

## Troubleshooting

### Controller Not Detected

```bash
# Check if controller is connected
ls /dev/input/js*

# Test joy node
ros2 run joy joy_enumerate_devices
ros2 topic echo /joy

# Check permissions
sudo chmod 666 /dev/input/js0
```

### Robot Not Responding

```bash
# Verify topics
ros2 topic list | grep -E "(cmd_vel|commands)"

# Check twist_mux status
ros2 topic echo /omnidirectional_controller/cmd_vel_unstamped

# Verify controllers are active
ros2 control list_controllers

# Enable debug logging
ros2 run llmy_teleop_xbox teleop_xbox.py --ros-args --log-level debug
```

### Arm Moving Unexpectedly

- Check stick calibration with `ros2 topic echo /joy`
- Increase `stick_deadband` parameter
- Verify arm controller is receiving commands

### Base Not Moving Smoothly

- Adjust `linear_scale` and `angular_scale`
- Check `acceleration_limit` parameter
- Verify omnidirectional controller configuration

## Dependencies

- `rclpy` - ROS2 Python client library
- `sensor_msgs` - Joy messages
- `geometry_msgs` - Twist messages
- `std_msgs` - Float64MultiArray messages
- `joy` - ROS2 joystick driver package

## Technical Details

### Command Publishing

- **Base**: Published at 50Hz with smooth acceleration limiting
- **Arm/Head**: Published at 30Hz with incremental position updates
- **Joystick**: Processed on every Joy message (typically 100Hz)

### Coordinate Frames

- Base commands use robot frame (forward = +X, left = +Y, CCW = +Z)
- Arm/head commands are joint angles in radians
- Camera pan: positive = right, negative = left
- Camera tilt: positive = up, negative = down

## License

Part of the LLMy Robot project. See main repository for license information.

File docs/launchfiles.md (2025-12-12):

# LLMy Launch Files Documentation

This document provides an overview of all launch files in the LLMy ROS 2 workspace and their parameters.

## Main System Launch Files

### llmy_bringup/launch/bringup_robot.launch.py
**Description**: Main modular launch file that coordinates all three subsystems (sensors, motion, communication).

**Parameters**:
- `use_sensors` (bool, default: `true`) - Enable all sensor systems
- `use_motion` (bool, default: `true`) - Enable motion and control systems  
- `use_communication` (bool, default: `true`) - Enable communication and web interfaces

**Includes**: sensors.launch.py, motion.launch.py, communication.launch.py

### llmy_bringup/launch/sensors.launch.py
**Description**: Sensor subsystem launch file (cameras, IMU, RPLidar).

**Parameters**:
- `use_camera` (bool, default: `true`) - Enable camera system (RealSense + wrist cam)
- `use_imu` (bool, default: `true`) - Enable IMU sensor
- `use_rplidar` (bool, default: `false`) - Enable RPLidar C1

**Includes**: camera.launch.py, imu.launch.py, rplidar_c1_launch.py

### llmy_bringup/launch/motion.launch.py
**Description**: Motion subsystem launch file (servos, ros2_control, teleop).

**Parameters**:
- `use_base_systems` (bool, default: `true`) - Enable servo manager (motor control)
- `use_control_stack` (bool, default: `true`) - Enable robot state publisher and controllers
- `use_xbox` (bool, default: `true`) - Enable Xbox controller teleoperation
- `servo_port` (string, default: `/dev/ttyTHS1`) - Serial port for servo communication
- `servo_baud` (string, default: `1000000`) - Baudrate for servo communication

**Includes**: servo_manager.launch.py, control_stack.launch.py, teleop_xbox.launch.py

### llmy_bringup/launch/communication.launch.py
**Description**: Communication subsystem launch file (rosbridge, rosboard, image compression).

**Parameters**:
- `use_rosbridge` (bool, default: `true`) - Enable rosbridge server for web interfaces
- `use_rosboard` (bool, default: `true`) - Enable rosboard web dashboard
- `use_image_compression` (bool, default: `true`) - Enable image compression and depth-to-scan

**Nodes**: rosbridge_websocket, rosboard_node, image compression nodes, depthimage_to_laserscan

## Control System Launch Files

### llmy_control/launch/base_systems.launch.py
**Description**: Launches base hardware systems including servo manager.

**Parameters**:
- `servo_port` (string, default: `/dev/ttyTHS1`) - Serial port for servo manager
- `servo_baud` (string, default: `1000000`) - Baudrate for servo manager
- `servo_config` (string, default: `''`) - Path to servo manager config file (uses package default if empty)

**Includes**: servo_manager.launch.py

### llmy_control/launch/control_stack.launch.py
**Description**: Launches the ros2_control stack with robot description and controllers.

**Parameters**: None

**Nodes**: robot_state_publisher, controller_manager, controller spawners (joint_state_broadcaster, diff_drive_controller, arm_controller, head_controller)

## Camera System Launch Files

### llmy_camera/launch/camera.launch.py
**Description**: Comprehensive camera setup with RealSense and USB wrist camera.

**Parameters**:
- `camera_name` (string, default: `head_camera`) - RealSense camera name
- `wrist_camera_device` (string, default: `/dev/video0`) - Wrist camera device path
- `enable_wrist_camera` (bool, default: `true`) - Enable wrist camera
- `device_type` (string, default: `''`) - RealSense device type (e.g., d435i, d455, l515)
- `enable_compressed` (bool, default: `false`) - Enable compressed image transport
- `enable_laser_scan` (bool, default: `false`) - Enable depth to laser scan conversion
- `laser_scan_min_height` (float, default: `-0.5`) - Minimum height for laser scan slice
- `laser_scan_max_height` (float, default: `0.5`) - Maximum height for laser scan slice
- `laser_scan_angle_min` (float, default: `-1.57`) - Minimum angle for laser scan (-90 degrees)
- `laser_scan_angle_max` (float, default: `1.57`) - Maximum angle for laser scan (+90 degrees)
- `laser_scan_angle_increment` (float, default: `0.005`) - Angular resolution of laser scan
- `laser_scan_range_min` (float, default: `0.2`) - Minimum range for laser scan
- `laser_scan_range_max` (float, default: `10.0`) - Maximum range for laser scan

**Includes**: realsense2_camera/launch/rs_launch.py

**Nodes**: wrist camera (usb_cam), RealSense camera

**Note**: Image compression and depth-to-scan are now handled by communication.launch.py

### llmy_camera/launch/realsense_only.launch.py
**Description**: Minimal RealSense camera setup.

**Parameters**:
- `camera_name` (string, default: `camera`) - RealSense camera name
- `device_type` (string, default: `d435i`) - RealSense device type

**Includes**: realsense2_camera/launch/rs_launch.py

## Sensor Launch Files

### llmy_imu/launch/imu.launch.py
**Description**: IMU sensor setup with Madgwick filter.

**Parameters**:
- `publish_rate` (float, default: `200.0`) - Publishing rate for IMU data in Hz
- `frame_id` (string, default: `imu_link`) - Frame ID for IMU data
- `use_mag` (bool, default: `true`) - Use magnetometer for orientation filtering

**Nodes**: imu_node, imu_filter_madgwick

## Teleop Launch Files

### llmy_teleop_xbox/launch/teleop_xbox.launch.py
**Description**: Xbox controller teleoperation setup.

**Parameters**:
- `joy_dev` (string, default: `0`) - Joystick device ID
- `switch_controllers` (bool, default: `true`) - Switch controllers flag

**Nodes**: joy_node, teleop_xbox (with controller command topics configured)

## Simulation Launch Files

### llmy_gazebo/launch/sim.launch.py
**Description**: Gazebo simulation environment setup.

**Parameters**:
- `gui` (bool, default: `true`) - Enable Gazebo GUI
- `pause` (bool, default: `false`) - Start simulation paused
- `spawn_z` (float, default: `0.05`) - Z position for robot spawn
- `cm_timeout` (string, default: `60`) - Controller manager timeout

**Includes**: gazebo_ros/launch/gzserver.launch.py, gazebo_ros/launch/gzclient.launch.py

**Nodes**: robot_state_publisher, spawn_entity, controller spawners (diff_drive_controller, arm_controller, head_controller - with event handlers for sequencing)

## Hardware Manager Launch Files

### llmy_servo_manager/launch/servo_manager.launch.py
**Description**: Servo motor manager for hardware communication.

**Parameters**:
- `config_file` (string, default: package config file) - Path to the servo manager config file
- `port` (string, default: `/dev/ttyUSB0`) - Serial port for motor communication
- `baud` (string, default: `2000000`) - Baud rate for serial communication

**Nodes**: servo_manager_node

### llmy_servo_manager/launch/test_brake_methods.launch.py
**Description**: Servo brake testing utility.

**Parameters**: 
- `config_file` (string, default: package config file) - Path to the servo manager config file
- `port` (string, default: `/dev/ttyUSB0`) - Serial port for motor communication  
- `baud` (string, default: `2000000`) - Baud rate for serial communication

**Nodes**: test_brake_methods

## Usage Examples

### Launch the complete robot system:
```bash
ros2 launch llmy_bringup bringup_robot.launch.py
```

### Launch with custom servo port:
```bash
ros2 launch llmy_bringup bringup_robot.launch.py servo_port:=/dev/ttyUSB1
```

### Launch desktop development environment:
```bash
ros2 launch llmy_bringup bringup_desktop.launch.py
```

### Launch simulation:
```bash
ros2 launch llmy_gazebo sim.launch.py
```

### Launch only camera system:
```bash
ros2 launch llmy_camera camera.launch.py
```

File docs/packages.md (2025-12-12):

# LLMy ROS Packages

| Package | Purpose | Language | Key Topics | Launch Command |
|---|---|---|---|---|
| **llmy_description** | Robot URDF model & transforms | XML/Python | `/robot_description`, `/tf`, `/joint_states` | `ros2 launch llmy_description view_robot.launch.py` |
| **llmy_servo_manager** | Direct motor control (C++) | C++ | `/motor_manager/*_cmd`, `/motor_manager/joint_states` | `ros2 launch llmy_servo_manager servo_manager.launch.py` |
| **llmy_servo_manager_py** | Motor control with advanced braking | Python | `/motor_manager/*_cmd`, `/motor_manager/joint_states` | `ros2 launch llmy_servo_manager_py servo_manager.launch.py` |
| **llmy_control_plugin** | ros2_control hardware bridge | C++ | `/cmd_vel`, `/arm_controller/joint_trajectory` | `ros2 launch llmy_control_plugin bringup.launch.py` |
| **llmy_teleop_xbox** | Xbox controller interface | Python | `/cmd_vel`, `/joy` | `ros2 launch llmy_teleop_xbox teleop_xbox.launch.py` |
| **llmy_control** | Controller configurations | YAML | N/A (config files) | Loaded by control_plugin |
| **llmy_camera** | RGB-D camera & vision | Python | `/head_camera/*`, `/scan`, `/wrist_camera/*` | `ros2 launch llmy_camera camera.launch.py` |
| **llmy_imu** | IMU sensor & fusion | Python | `/imu/data`, `/imu/fused` | `ros2 launch llmy_imu imu.launch.py` |

### 📦 Detailed Package Information

#### **📐 llmy_description - Robot Model**

**What it does:** Provides the complete URDF/Xacro robot model with accurate physical properties, joint limits, collision meshes, and visual representations. This is the "digital twin" of your physical robot.

**Nodes launched:**
- `robot_state_publisher` - Publishes robot transforms and joint states
- `joint_state_publisher` - (Optional) For manual joint control in simulation

**How to run:**
```bash
# Standalone URDF visualization
ros2 launch llmy_description view_robot.launch.py

# Load robot model for other packages
ros2 run robot_state_publisher robot_state_publisher --ros-args -p robot_description:="$(xacro $(ros2 pkg prefix llmy_description)/share/llmy_description/urdf/llmy.urdf.xacro)"
```

**Key topics:**
- `/robot_description` - URDF robot model
- `/tf` and `/tf_static` - Robot transforms
- `/joint_states` - Current joint positions

#### **🔧 llmy_servo_manager - Direct Motor Control (C++)**

**What it does:** Handles low-level communication with FEETECH STS servos via serial protocol. Converts ROS2 joint commands into servo-specific position/velocity commands and provides real-time telemetry feedback.

**Nodes launched:**
- `servo_manager_node` - Main servo communication node
- `ping_test` - (Optional) Motor connectivity testing utility

**How to run:**
```bash
# Main servo manager (requires hardware)
ros2 launch llmy_servo_manager servo_manager.launch.py

# Test motor connectivity
ros2 launch llmy_servo_manager ping_test.launch.py

# Custom serial port
ros2 launch llmy_servo_manager servo_manager.launch.py port:=/dev/ttyTHS1 baud:=1000000
```

**Key topics:**
- `/motor_manager/base_cmd` - Base motor velocity commands
- `/motor_manager/arm_cmd` - Arm motor position commands  
- `/motor_manager/head_cmd` - Head motor position commands
- `/motor_manager/joint_states` - Motor telemetry feedback

**Configuration:** Edit `config/servo_manager.yaml` to adjust motor IDs, serial settings, and control parameters.

---

#### **🐍 llmy_servo_manager_py - Python Motor Control**

**What it does:** Python-based alternative to the C++ servo manager with modular architecture, advanced braking system, and improved error handling. Provides the same functionality with enhanced safety features and easier customization.

**Features:**
- **Advanced Braking System**: Three configurable braking methods to prevent power spikes
- **Modular Architecture**: Clean separation of motor management, configuration, and command handling
- **Improved Safety**: Comprehensive connectivity testing and graceful error recovery
- **Enhanced Telemetry**: Detailed motor state monitoring and diagnostics

**Nodes launched:**
- `servo_manager_node.py` - Main Python servo manager node

**How to run:**
```bash
# Main Python servo manager (requires hardware)
ros2 launch llmy_servo_manager_py servo_manager.launch.py

# Test brake methods
ros2 launch llmy_servo_manager_py test_brake_methods.launch.py

# Custom configuration
ros2 launch llmy_servo_manager_py servo_manager.launch.py config_file:=custom_config.yaml
```

**Key topics:** (Same as C++ version)
- `/motor_manager/base_cmd` - Base motor velocity commands
- `/motor_manager/arm_cmd` - Arm motor position commands  
- `/motor_manager/head_cmd` - Head motor position commands
- `/motor_manager/joint_states` - Motor telemetry feedback

**Configuration:** Edit `config/servo_manager.yaml` to adjust motor IDs, serial settings, braking method, and control parameters.

> **💡 When to use:** Choose the Python version for enhanced safety features, easier customization, or when you need advanced braking control. Both versions are fully compatible with the rest of the system.

---

#### **🔌 llmy_control_plugin - Hardware Bridge**

**What it does:** Acts as the ros2_control hardware interface, bridging standard ROS2 controllers with the servo manager. Enables seamless integration with MoveIt2, navigation, and other ROS2 tools.

**Nodes launched:**
- `controller_manager` - ros2_control manager
- `diff_drive_controller` - Base movement controller (skid-steer)
- `arm_controller` - Arm trajectory controller
- `joint_state_broadcaster` - Joint state publisher

**How to run:**
```bash
# Launch with hardware interface
ros2 launch llmy_control_plugin bringup.launch.py

# Simulation mode (requires Gazebo)
ros2 launch llmy_control_plugin bringup.launch.py use_sim_time:=true
```

**Key topics:**
- `/cmd_vel` - Base velocity commands (input)
- `/arm_controller/joint_trajectory` - Arm trajectory commands (input)
- `/joint_states` - Combined joint states (output)
- `/controller_manager/*` - Controller status and management

---

#### **🎮 llmy_teleop_xbox - Manual Control**

**What it does:** Provides intuitive Xbox controller mapping for manual robot operation. Maps controller inputs to robot movements with safety limits and smooth control.

**Nodes launched:**
- `teleop_xbox_node` - Xbox controller interface
- `joy_node` - Joystick driver

**How to run:**
```bash
# Standard Xbox controller
ros2 launch llmy_teleop_xbox teleop_xbox.launch.py

# Custom controller device
ros2 launch llmy_teleop_xbox teleop_xbox.launch.py device:=/dev/input/js1
```

**Controller mapping:**
- **Right stick:** Base movement (forward/back + rotation)
- **RB/LB:** Arm joint 1 (+/-)
- **RT/LT:** Arm joint 2 (+/-)
- **Y/A:** Arm joint 3 (+/-)
- **B/X:** Arm joint 4 (+/-)
- **Start/Back:** Arm joint 5 (+/-)
- **Stick clicks:** Arm joint 6 (+/-)
- **D-pad up/down:** Camera pan
- **D-pad left/right:** Camera tilt

**Key topics:**
- `/cmd_vel` - Base velocity output
- `/arm_controller/joint_trajectory` - Arm movement output
- `/joy` - Raw joystick data

---

#### **⚙️ llmy_control - Controller Configuration**

**What it does:** Provides controller configurations and parameter files for the skid-steer differential drive base and 6-DOF arm using standard ros2_control patterns.

**Configuration files:**
- `config/controllers.yaml` - Controller parameters
- `config/ros2_control.yaml` - Hardware interface config
- `config/joint_limits.yaml` - Safety limits

**Loaded by:** llmy_control_plugin (no standalone launch)

**Key parameters:**
- Velocity limits for base wheels
- Position/velocity limits for arm joints
- Controller gains and dynamics

#### **📷 llmy_camera - Vision System**

**What it does:** Integrates RGB-D cameras with compressed image transport and depth-to-laser conversion. Provides both manipulation-ready RGB-D data and navigation-ready 2D laser scans.

**Nodes launched:**
- `realsense2_camera_node` - RealSense D435 driver
- `depthimage_to_laserscan` - Depth to 2D scan converter
- `image_transport` - Compressed image streaming
- `usb_cam_node` - (Optional) Wrist camera driver

**How to run:**
```bash
# Full camera system
ros2 launch llmy_camera camera.launch.py

# RealSense only
ros2 launch llmy_camera realsense.launch.py

# With custom resolution
ros2 launch llmy_camera camera.launch.py width:=1280 height:=720
```

**Key topics:**
- `/head_camera/color/image_raw` - RGB images
- `/head_camera/depth/image_rect_raw` - Depth images
- `/head_camera/rgbd` - Combined RGB-D data
- `/scan` - 2D laser scan from depth
- `/wrist_camera/image_raw` - Wrist camera feed

---

#### **📐 llmy_imu - Orientation Sensing**

**What it does:** Handles ICM20948 9-DOF sensor integration with Madgwick sensor fusion, providing calibrated orientation data crucial for navigation and balance.

**Nodes launched:**
- `imu_filter_madgwick` - Sensor fusion node
- `icm20948_driver` - Raw IMU data driver

**How to run:**
```bash
# IMU with sensor fusion
ros2 launch llmy_imu imu.launch.py

# Raw IMU data only
ros2 run llmy_imu icm20948_driver
```

**Key topics:**
- `/imu/data` - Raw IMU measurements
- `/imu/fused` - Fused orientation estimate
- `/imu/mag` - Magnetometer data

**Calibration:** Run calibration sequence on first setup:
```bash
ros2 run llmy_imu calibrate_imu
```

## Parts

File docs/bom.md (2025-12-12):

# LLMy Bill of Materials (BOM)

This document provides a comprehensive breakdown of all components needed to build LLMy, with pricing and sourcing information for both US and EU markets.

#### 🤖 Main Platform
| Part | Amount | Unit Cost (US) | Buy (US) | Unit Cost (EU) | Buy (EU) | Total(US) | Total(EU) |
|:---|:---:|:---:|:---|:---:|---:|:-:|-|
| 12V ST3215 Feetech Servo | 12 | $13.89 | [Alibaba](https://www.alibaba.com/product-detail/Feetech-STS3215-SO-ARM100-Servo-12V_1601292634404.html) | €13.38 | [Alibaba EU](https://www.alibaba.com/product-detail/Feetech-STS3215-SO-ARM100-Servo-12V_1601292634404.html) | $166.68 | €160.56 |
| WaveShare ESP32 Servo Controller | 1 | $10.55 | [Amazon](https://www.amazon.com/Expansion-Bluetooth-Control-Application-Structures/dp/B0CKT8BN73) | €4.76 | [Kamami](https://kamami.pl/en/Servo-Controllers/1187948-serial-bus-servo-driver-board-integrates-servo-power-supply-and-control-circuit-applicable-for-st-5906623428014.html) | $10.55 | €4.76 |
| Adafruit USB-PD Trigger | 2 | $5.95 | [Adafruit](https://www.adafruit.com/product/5807) | €6.90 | [Kamami](https://kamami.pl/en/wyzwalacze-usb-pd-elektonika/1188206-usb-type-c-power-delivery-dummy-breakout-module-with-usb-type-c-power-delivery-husb238-power-supply-control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) | $11.90 | €13.80 |
| Adafruit ICM20948 IMU | 1 | $14.95 | [Adafruit](https://www.adafruit.com/product/4554) | €18.91 | [Kamami](https://kamami.pl/en/sensors-6dof-9dof-10dof/587247-stemma-qt-tdk-invensense-icm-20948-9-dof-imu-module-with-9-dof-sensor-icm-20948-adafruit-4554-5906623430239.html) | $14.95 | €18.91 |
| Baseus GP12 Battery Pack (145W, 20.8Ah) | 1 | $59.99 | [Amazon](https://www.amazon.com/Baseus-20800mAh-Portable-Charger-Charging/dp/B0DQTYLGYK) | €48.99 | [Baseus EU](https://eu.baseus.com/products/energeek-gp12-power-bank-145w-20800mah) | $59.99 | €48.99 |
| **Total Base Platform** | | | | | | **$264.07** | **€247.02** |

#### 📷 RGB-D Cameras

**The core perception system** for LLMy uses RGB-D cameras that provide both color and depth information. This enables rich scene understanding for AI inference, manipulation, and navigation.

> 💡 **Why RGB-D?** A single sensor provides object identification with distance/size estimation. The depth stream supports multiple SLAM approaches: RGB-SLAM, RGB-D SLAM, or 2D SLAM via `depthimage_to_laserscan`.

All software is built on the **Intel RealSense SDK** and ROS driver, but other depth cameras serve as near drop-in replacements.

| Part | Unit Cost (US) | Buy (US) | Unit Cost (EU) | Buy (EU) | Robot + Camera (US) | Robot + Camera (EU) |
|---|---:|:---|---:|:---|---:|---:|
| **YDLidar HP60C** | $202.00 | [RobotShop US](https://www.robotshop.com/products/ydlidar-hp60c-compact-lidar-sensor-02-4m-range-73-8-scan-angle) | €190.00 | [RobotShop EU](https://eu.robotshop.com/products/ydlidar-hp60c-compact-lidar-sensor-02-4m-range-73-8-scan-angle) | **$466.07** | **€437.02** |
| **Orbbec Gemini 2** | $234.00 | [Orbbec Store](https://store.orbbec.com/products/gemini-2) | €230.00 | [Orbbec EU](https://store.orbbec3d.com) | **$498.07** | **€477.02** |
| **Intel RealSense D415** | $272.00 | [RealSense Store](https://store.realsenseai.com/buy-intel-realsense-depth-camera-d415.html) | €310.00 | [Mouser EU](https://eu.mouser.com/ProductDetail/Intel/82635AWGDVKPRQ) | **$536.07** | **€557.02** |
| **Intel RealSense D435** | $314.00 | [RealSense Store](https://store.realsenseai.com/buy-intel-realsense-depth-camera-d435.html) | €317.60 | [Mouser EU](https://eu.mouser.com/ProductDetail/Intel/82635AWGDVKPRQ) | **$578.07** | **€564.62** |
| **Stereolabs ZED 2i** | $499.00 | [Stereolabs Store](https://store.stereolabs.com/products/zed-2i) | €449.00 | [Stereolabs EU](https://store.stereolabs.com/products/zed-2i) | **$763.07** | **€696.02** |

#### 💻 Single Board Computers & Mini-PCs

**Recommended:** Nvidia Orin Nano Super for optimal AI performance. The battery pack delivers up to **65W per power lane** at **20V**, supporting a wide range of compute options:

| Option | Power Draw | Performance | Best For |
|---|---|---|---|
| 🥧 **Raspberry Pi 5** | ~15W | Basic | Learning, simple tasks |
| 🚀 **Nvidia Orin Nano** | ~25W | 67 TOPS of AI performace  | AI/ML inference |
| 💪 **Intel NUC** | ~30-45W | Better, Desktop Class CPU| General compute, ROS2 |
| 🔧 **Custom Mini-PC** | <65W | Variable | Specific requirements |

> 💡 **Power Note:** Any device requiring ≤65W and compatible with 20V USB-C PD will work.

## 🔧 Optional Components

### 📡 LIDAR Sensor

<div align="center">
  RPLidar C1
</div>

While RGB-D cameras provide 2D scan data via `depthimage_to_laserscan`, they typically have a 30cm minimum range blind spot. A dedicated LIDAR sensor offers:

- **Enhanced Navigation** - Better obstacle avoidance and SLAM
- **Close-Range Detection** - No minimum distance limitations
- **Simpler Processing** - Direct 2D scan data without conversion
- **Reliability** - Consistent performance in various lighting conditions

#### Recommended LIDAR Options

| Model | Range | Price (US) | Price (EU) | Buy |
|---|---|---|---|---|
| **SLAMTEC RPLidar C1** | 0.1-12m | $89 | €79 | [Kamami EU](https://kamami.pl/en/laser-scanner/1189121-slamtec-rplidar-c1-laser-ranging-sensor-360-omnidirectional-lidar-millimeter-level-high-definitio-5906623483501.html) |
| **YDLIDAR X2L** | 0.12-8m | $99 | €89 | [RobotShop](https://www.robotshop.com/products/ydlidar-x2l-lidar-scanner) |

> 💡 **Installation:** LIDAR mounts on the camera tower with provided brackets.

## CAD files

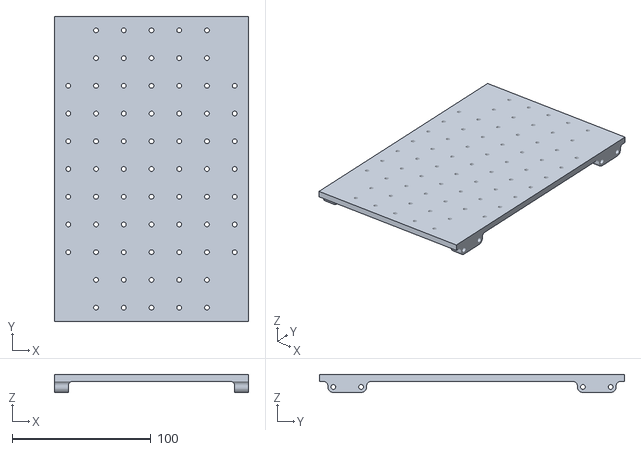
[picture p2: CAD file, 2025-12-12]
ros/src/llmy_description/meshes/modular_floor_full_v1_1.stl
140.0 x 220.0 x 13.0

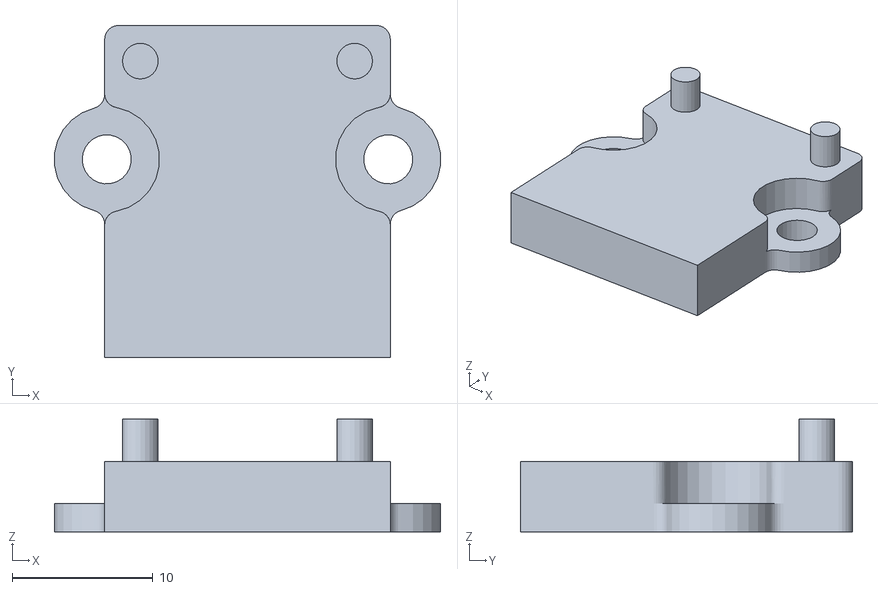
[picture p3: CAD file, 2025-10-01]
parts/base/adafruit_usb_pd_mount.stl
27.4 x 23.6 x 8.00

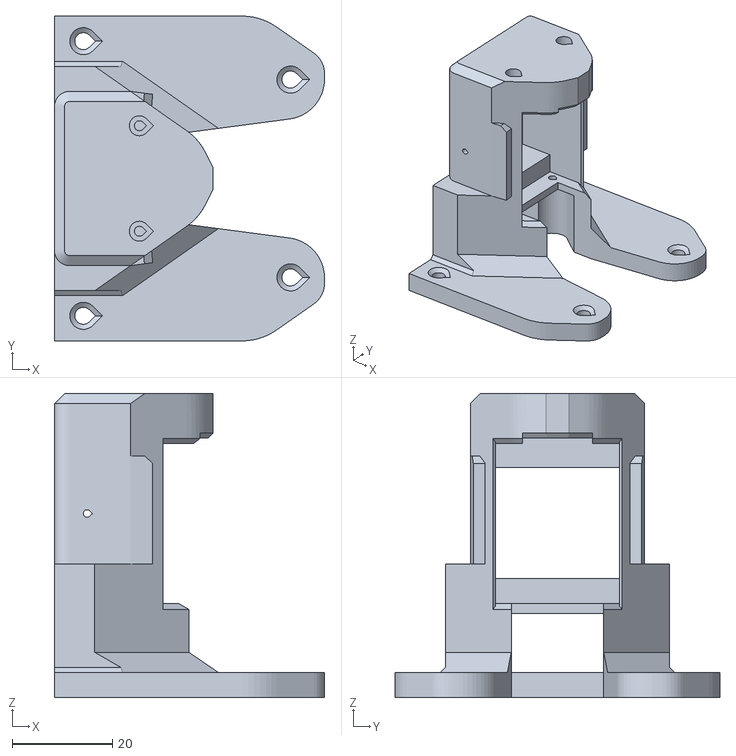
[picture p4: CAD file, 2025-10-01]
parts/camera_tower/pan_and_tilt_support.stl
53.8 x 64.7 x 60.5

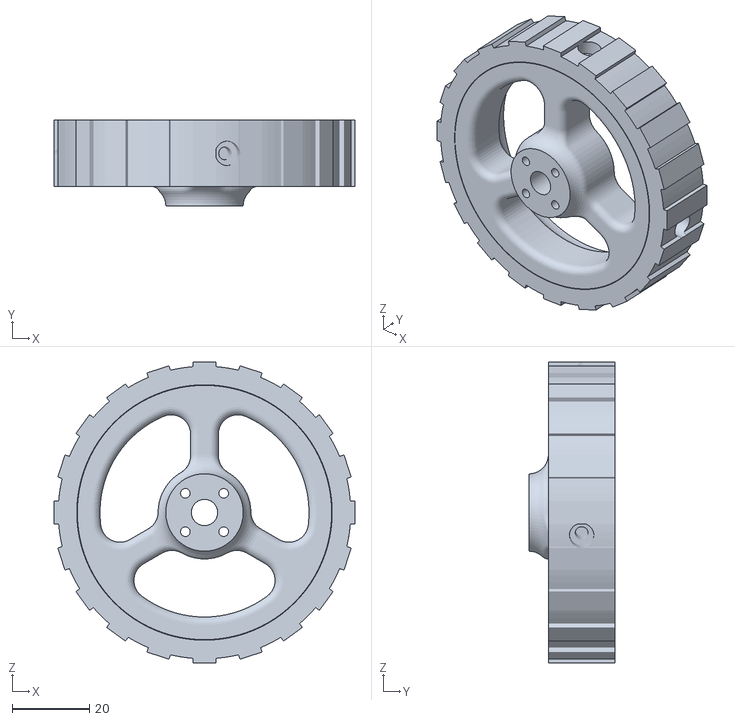
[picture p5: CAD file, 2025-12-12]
ros/src/llmy_description/meshes/BL_wheel_1.stl
77.8 x 22.2 x 77.8

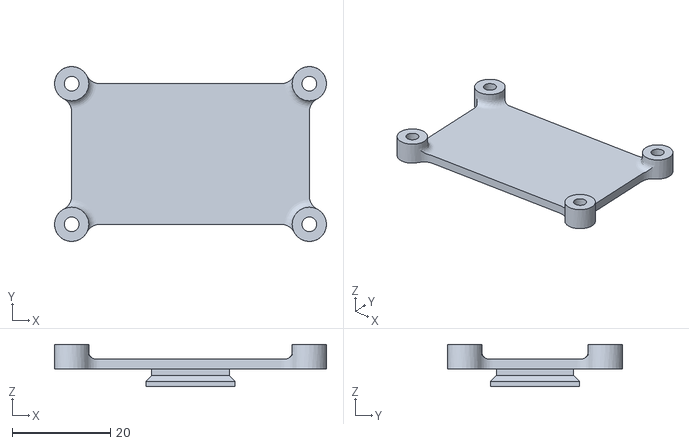
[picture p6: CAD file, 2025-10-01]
parts/base/fe_urt_1_mount.stl
55.5 x 35.7 x 8.60

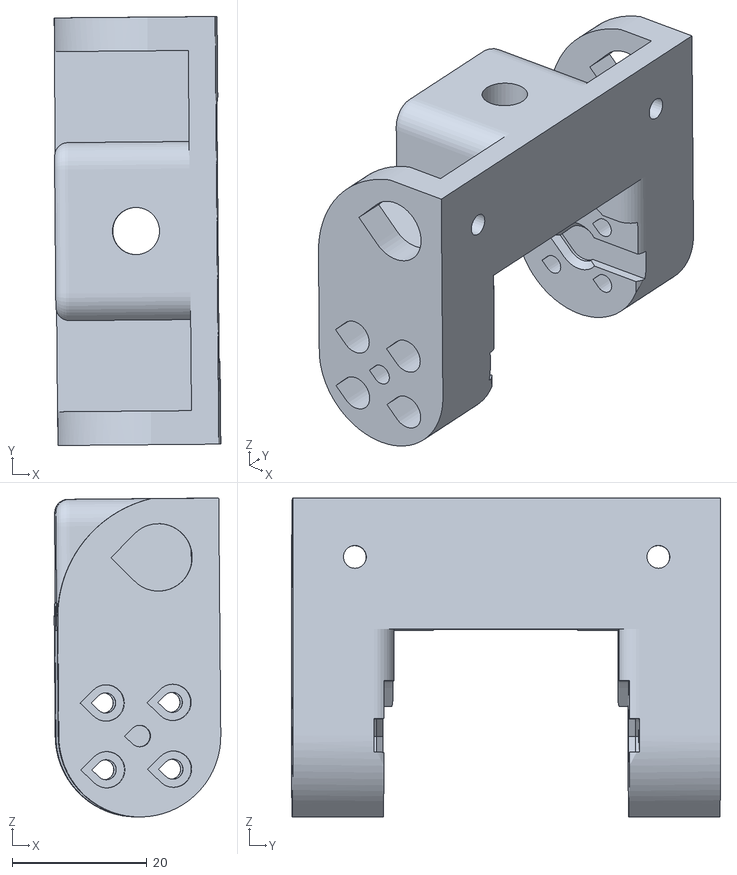
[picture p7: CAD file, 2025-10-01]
parts/camera_tower/realsense_support v1.stl
24.7 x 63.6 x 47.3

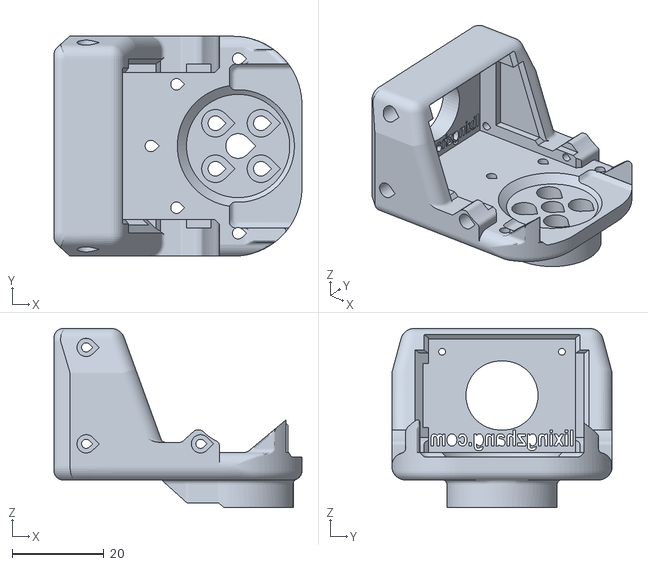
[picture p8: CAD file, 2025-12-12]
ros/src/llmy_description/meshes/camera_plm_v1_1.stl
54.0 x 48.0 x 39.0

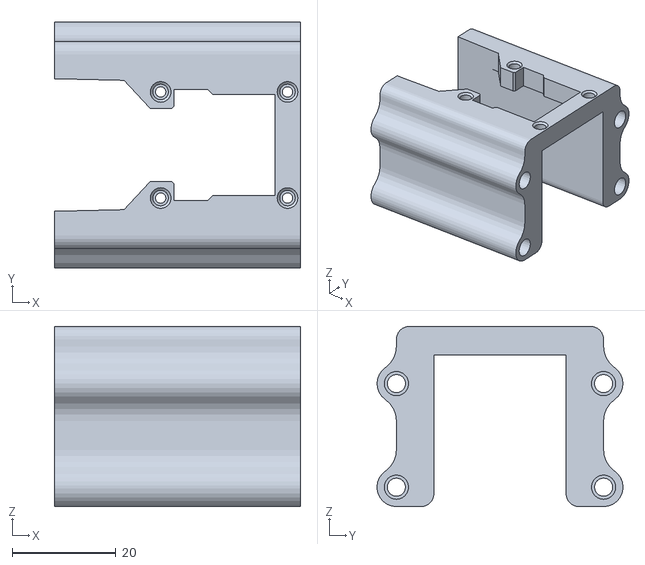
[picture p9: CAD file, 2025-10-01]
parts/base/servo_mount.stl
47.5 x 47.5 x 34.8

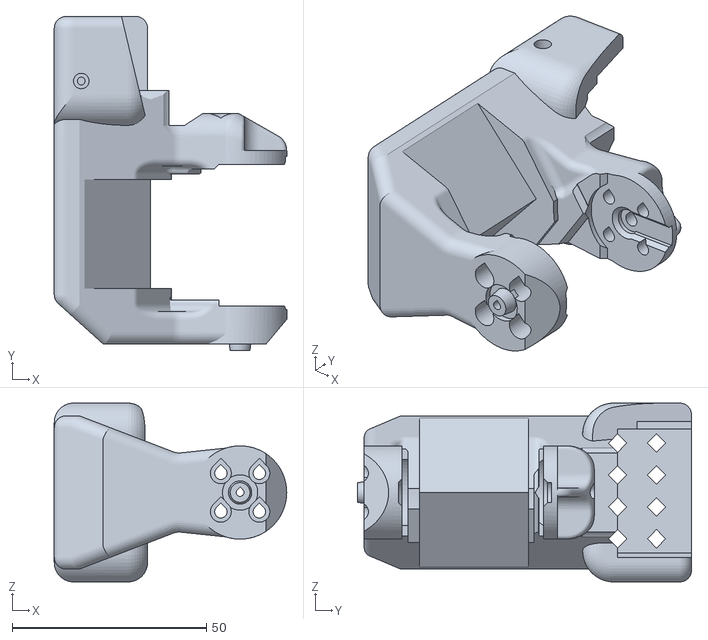
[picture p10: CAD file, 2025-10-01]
parts/camera_tower/pan_link.stl
59.8 x 85.9 x 46.0

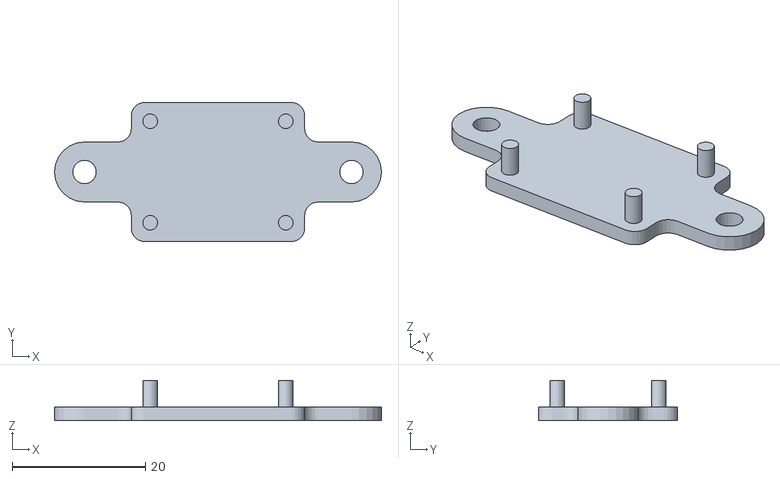
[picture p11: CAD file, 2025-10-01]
parts/base/adafruit_i2c_switch_mount.stl
49.0 x 20.9 x 6.00

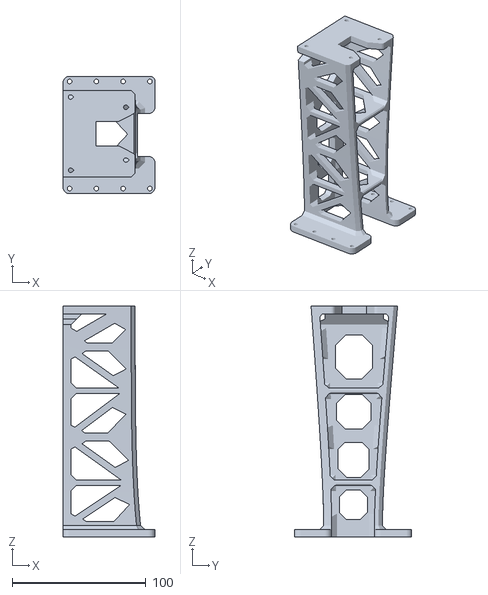
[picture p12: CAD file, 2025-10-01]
parts/camera_tower/tower.stl
68.9 x 87.7 x 172.6

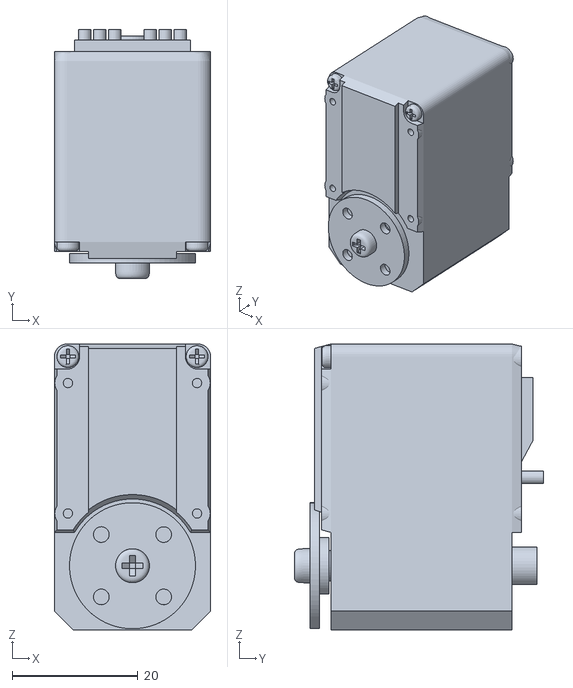
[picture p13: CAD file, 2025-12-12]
ros/src/llmy_description/meshes/FR_motor_1.stl
24.8 x 39.6 x 45.4

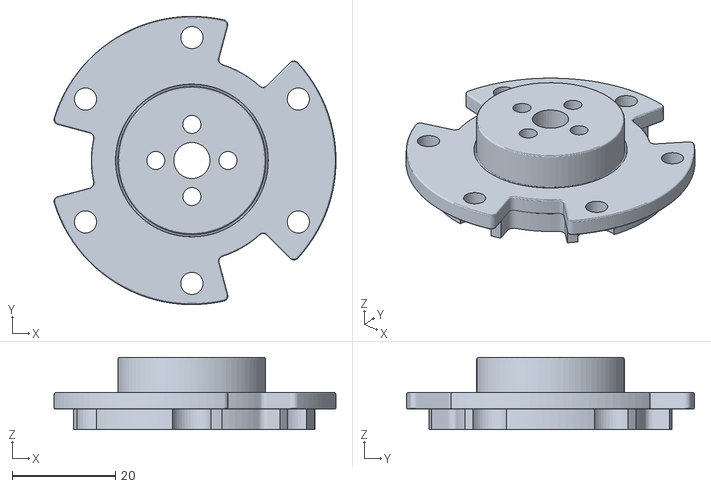
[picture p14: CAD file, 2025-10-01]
parts/base/wheel_hub.stl
54.7 x 55.9 x 14.0

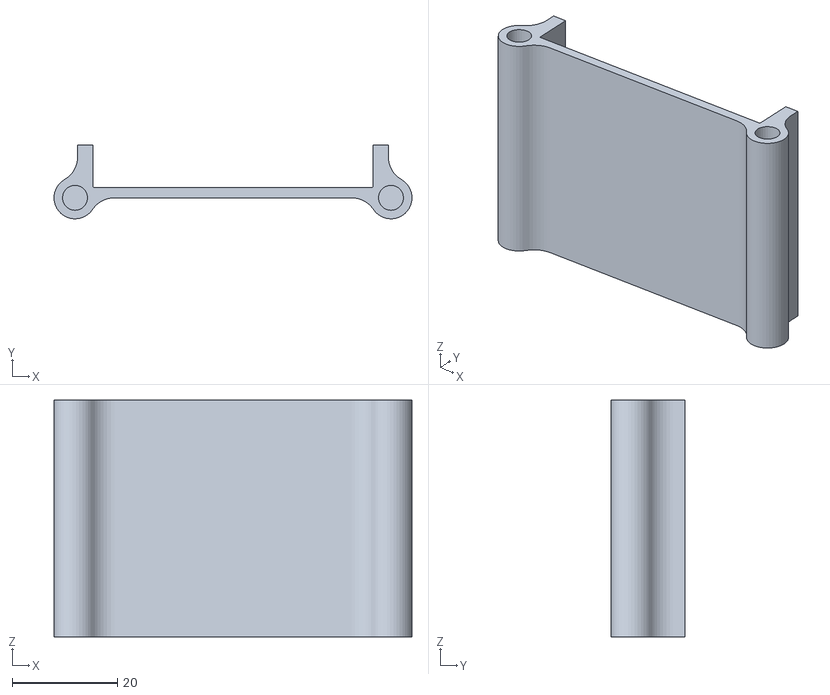
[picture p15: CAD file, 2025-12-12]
ros/src/llmy_description/meshes/right_baseus_mount_v1_1.stl
68.0 x 14.0 x 45.0

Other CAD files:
parts/base/adafruit_icm_mount.stl
ros/src/llmy_description/meshes/FL_motor_1.stl
parts/base/baseus_left.stl
ros/src/llmy_description/meshes/base_servo_cover_1.stl
parts/base/base_plate.stl
parts/base/battery_left.stl
parts/base/battery_right.stl
parts/base/imu_mount.stl
parts/base/lidar_mount.stl
parts/base/orin_mount.stl
parts/base/second_plate.stl
parts/base/third_plate.stl
ros/src/llmy_description/meshes/BL_motor_1.stl
ros/src/llmy_description/meshes/BR_motor_1.stl
ros/src/llmy_description/meshes/BR_wheel_1.stl
ros/src/llmy_description/meshes/FL_wheel_1.stl
ros/src/llmy_description/meshes/FR_wheel_1.stl
ros/src/llmy_description/meshes/arm_base_rotation_link_1.stl
ros/src/llmy_description/meshes/arm_base_rotation_link_cover_1.stl
ros/src/llmy_description/meshes/arm_base_rotation_servo_1.stl
ros/src/llmy_description/meshes/arm_elbow_link_1.stl
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

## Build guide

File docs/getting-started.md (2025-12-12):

# Getting Started with LLMy

This guide walks you through setting up LLMy from your first simulation to running on real hardware.

## Prerequisites

### System Requirements
- **OS:** Ubuntu 22.04 LTS
- **ROS2:** Humble Hawksbill
- **Simulator:** Gazebo Classic (for simulation)

### Hardware Requirements (Real Robot Only)
- FEETECH STS3215 servos (12x)
- Serial motor controller (FE-URT-1 or Waveshare adapter)
- USB-C power bank (145W with PD trigger)
- Single-board computer (Raspberry Pi 5 or Jetson Orin Nano)

### Optional Peripherals
- Xbox controller (for teleoperation)
- RealSense D435i / ZED 2i / Orbbec Gemini 2 (RGB-D camera)
- ICM-20948 IMU
- RPLidar C1 (LIDAR)

---

## Installation

### 1. Install ROS2 Humble

If you don't have ROS2 Humble installed:

```bash
sudo apt update && sudo apt install -y software-properties-common
sudo add-apt-repository universe
sudo apt update && sudo apt install -y curl
sudo curl -sSL https://raw.githubusercontent.com/ros/rosdistro/master/ros.key -o /usr/share/keyrings/ros-archive-keyring.gpg
echo "deb [arch=$(dpkg --print-architecture) signed-by=/usr/share/keyrings/ros-archive-keyring.gpg] http://packages.ros.org/ros2/ubuntu $(. /etc/os-release && echo $UBUNTU_CODENAME) main" | sudo tee /etc/apt/sources.list.d/ros2.list > /dev/null
sudo apt update
sudo apt install -y ros-humble-desktop
```

### 2. Clone LLMy

```bash
git clone https://github.com/cristidragomir97/llmy.git llmy_ws
cd llmy_ws/ros
```

### 3. Install Dependencies

```bash
# Install vcstool for managing repository dependencies
sudo apt install -y python3-vcstool

# Import external ROS2 packages (diff drive controllers, rplidar)
vcs import src < repos.vcs

# Install all workspace dependencies
rosdep install --from-paths src --ignore-src -r -y

# Optional: Install additional hardware support packages
sudo apt install -y \
    ros-humble-realsense2-camera \
    ros-humble-compressed-image-transport \
    ros-humble-depthimage-to-laserscan \
    ros-humble-imu-filter-madgwick
```

### 4. Build the Workspace

```bash
colcon build --symlink-install
source install/setup.bash
```

**Tip:** Add `source ~/llmy_ws/ros/install/setup.bash` to your `~/.bashrc` to automatically source the workspace.

---

## Simulation Quickstart

The fastest way to see LLMy in action is through Gazebo simulation.

### Launch the Simulation

```bash
# Terminal 1: Start Gazebo with the robot
ros2 launch llmy_gazebo sim.launch.py
```

You should see the robot spawn in Gazebo with all controllers loaded.

### Control with Xbox Controller (Optional)

```bash
# Terminal 2: Launch Xbox teleop
ros2 launch llmy_teleop_xbox teleop_xbox.launch.py
```

**Controller Mapping:**
- **Right Stick:** Drive base (forward/back + rotation)
- **RB/LB Buttons:** Arm joint 1 (+/-)
- **RT/LT Triggers:** Arm joint 2 (+/-)
- **Y/A Buttons:** Arm joint 3 (+/-)
- **B/X Buttons:** Arm joint 4 (+/-)
- **Start/Back Buttons:** Arm joint 5 (+/-)
- **Stick Clicks:** Arm joint 6 (+/-)
- **D-Pad Up/Down:** Camera pan
- **D-Pad Left/Right:** Camera tilt

### Verify Controllers are Running

```bash
# List active controllers
ros2 control list_controllers

# Expected output:
# arm_controller[joint_trajectory_controller/JointTrajectoryController] active
# diff_drive_controller[diff_drive_controller/DiffDriveController] active
# head_controller[joint_trajectory_controller/JointTrajectoryController] active
```

---

## Hardware Setup

### Step 1: Configure Servo IDs

Before assembly, configure all servo IDs and mark them physically.

```bash
cd ~/llmy_ws/scripts

# Interactive mode - connect servos one at a time
python3 set_servo_id.py
```

**ID Assignment:**
- Base (drivetrain): **1, 2, 3, 4**
- Arm joints: **5, 6, 7, 8, 9, 10**
- Head (pan/tilt): **11, 12**

**Mark each servo** with a pen/marker after setting its ID to avoid confusion during assembly.

**Verify all servos:**
```bash
python3 set_servo_id.py --list
```

See [`scripts/README.md`](../scripts/README.md) for detailed instructions.

### Step 2: Build Software & Test Before Assembly

Build the ROS workspace and verify servo communication before physical assembly.

```bash
cd ~/llmy_ws/ros
colcon build --symlink-install
source install/setup.bash
```

**Test servo connectivity:**
```bash
# Connect all servos via daisy-chain temporarily
ros2 launch llmy_servo_manager ping_test.launch.py
```

This ensures all electronics work before you commit to full assembly.

### Step 3: Physical Assembly

**Required Tools:**
- Soldering iron (for heat-set inserts)
- M3 screws and hex wrenches
- Marker/pen (for labeling)

**Assembly Sequence:**

#### Step 1: Prepare Structural Parts
Insert M3 heat-set nuts using a soldering iron into:
- [servo_mount.stl](../parts/base/servo_mount.stl) (base wheel mounts)
- [battery_left.stl](../parts/base/battery_left.stl) (battery holder left side)
- [battery_right.stl](../parts/base/battery_right.stl) (battery holder right side)

#### Step 2: Drivetrain Assembly
- Install [wheel_hub.stl](../parts/base/wheel_hub.stl) on drivetrain servos **(IDs 1, 2, 3, 4)**
- Attach standard wheels to hubs
- Mount servos into [servo_mount.stl](../parts/base/servo_mount.stl)

#### Step 3: Base Platform
- Mount the four drivetrain assemblies to the base plate:
  - **Servo ID 1** → Front-left position
  - **Servo ID 2** → Back-left position
  - **Servo ID 3** → Front-right position
  - **Servo ID 4** → Back-right position
- Install battery mounts ([battery_left.stl](../parts/base/battery_left.stl), [battery_right.stl](../parts/base/battery_right.stl))
- If using LiDAR: mount to [lidar_mount.stl](../parts/base/lidar_mount.stl)
- Slide USB-C power bank into battery holder slot

#### Step 4: Arm Assembly
Assemble the 6-DOF arm following the [official SO-ARM100 instructions](https://www.hiwonder.com/products/so-arm100).
- Use servos **IDs 5-10** in order from base to gripper
- Ensure servo horns are centered before assembly

#### Step 5: Second Floor Integration
Mount on the second floor platform:
- Assembled robot arm
- Single-board computer (Raspberry Pi 5 or Jetson Orin Nano) with [orin_mount.stl](../parts/base/orin_mount.stl)
- USB-PD trigger modules (2x for 12V power) with [adafruit_usb_pd_mount.stl](../parts/base/adafruit_usb_pd_mount.stl)
- IMU sensor (ICM-20948) with [adafruit_icm_mount.stl](../parts/base/adafruit_icm_mount.stl)
- I2C switch module with [adafruit_i2c_switch_mount.stl](../parts/base/adafruit_i2c_switch_mount.stl)
- Motor controller with [fe_urt_1_mount.stl](../parts/base/fe_urt_1_mount.stl)

#### Step 6: Wiring - First Pass
- Route servo wires through cable management holes
- Create daisy-chain starting from **base servo 1** → continuing through all servos → ending at **camera tilt servo (ID 12)**
- Leave one free connector at the start (will connect to motor controller)
- Verify you have a clean daisy-chain from base to camera

#### Step 7: Camera Tower
- Assemble pan-tilt mechanism using head servos **(IDs 11, 12)**
- Mount to camera tower structure
- Attach RGB-D camera (RealSense/ZED/Orbbec)
- Install tower on top floor platform

#### Step 8: Motor Controller Placement
- Mount FE-URT-1 or Waveshare servo controller to the back of the arm base using [fe_urt_1_mount.stl](../parts/base/fe_urt_1_mount.stl) or [WaveShare_Mounting_Plate_SO101.stl](https://github.com/TheRobotStudio/SO-ARM100/blob/main/STL/SO101/Individual/WaveShare_Mounting_Plate_SO101.stl)
- Connect daisy-chain free connector to controller output
- Connect controller to SBC via USB or UART

#### Step 9: Complete Wiring
- **Power:**
  - USB-PD module 1 → SBC (12V or 5V depending on trigger)
  - USB-PD module 2 → Motor controller (12V)
- **Data:**
  - Camera → SBC (USB)
  - IMU → SBC (I2C)
  - Motor controller → SBC (USB or UART)
  - LiDAR → SBC (USB, if installed)
- **Organize cables** with zip ties and ensure nothing interferes with moving parts

**Assembly Tips:**
- Double-check servo IDs before installation
- Test each servo individually before daisy-chaining
- Leave slack in wiring for joint movement
- Use cable management holes to prevent wire snagging
- Take photos during assembly for reference

### Step 4: Calibrate the Arm

After assembly, calibrate the arm's zero position and joint limits.

**⚠️ Important:** Stop any running ROS nodes first:
```bash
pkill -f servo_manager
```

**Run calibration wizard:**
```bash
cd ~/llmy_ws/scripts
python3 calibrate_arm.py --config ~/llmy_ws/ros/src/llmy_servo_manager/config/servo_manager.yaml
```

**Calibration process:**
1. Position arm fully erect (vertical) with gripper closed → set zero position
2. For each joint, move to minimum position → record limit
3. For each joint, move to maximum position → record limit
4. Script saves calibration data to config file

This ensures safe operation by preventing the arm from exceeding physical limits.

See [`scripts/README.md`](../scripts/README.md) for detailed calibration instructions.

### Step 5: Launch the Robot

Configure serial port access:

```bash
# Give user permission for serial port
sudo usermod -a -G dialout $USER
# Log out and back in for changes to take effect

# Identify your servo controller port
ls /dev/ttyUSB* /dev/ttyACM* /dev/ttyTHS*
```

**Common ports:**
- `/dev/ttyUSB0` - USB adapter
- `/dev/ttyACM0` - USB CDC adapter
- `/dev/ttyTHS1` - Jetson hardware UART

Update port in config if needed:
```bash
nano ~/llmy_ws/ros/src/llmy_servo_manager/config/servo_manager.yaml
# Change: port: "/dev/ttyTHS1" to your port
```

**Launch the complete robot system:**

**Single-command bringup (recommended):**

```bash
ros2 launch llmy_bringup bringup_robot.launch.py
```

**With custom serial configuration:**

```bash
ros2 launch llmy_bringup bringup_robot.launch.py \
    servo_port:=/dev/ttyUSB0 \
    servo_baud:=1000000
```

**Disable specific subsystems:**

```bash
ros2 launch llmy_bringup bringup_robot.launch.py \
    use_camera:=false \
    use_xbox:=false
```

### Launch Components Individually (Advanced)

For debugging or custom configurations, launch subsystems separately:

```bash
# Terminal 1: Servo manager (low-level motor control)
ros2 launch llmy_control base_systems.launch.py

# Terminal 2: Hardware interface & controllers
ros2 launch llmy_control_plugin bringup.launch.py

# Terminal 3: Camera system (optional)
ros2 launch llmy_camera camera.launch.py

# Terminal 4: IMU sensor (optional)
ros2 launch llmy_imu imu.launch.py

# Terminal 5: Xbox controller (optional)
ros2 launch llmy_teleop_xbox teleop_xbox.launch.py
```

---

## Verification & Testing

### Check System Status

```bash
# Verify all controllers are active
ros2 control list_controllers

# List active ROS2 topics
ros2 topic list

# Monitor system diagnostics
ros2 topic echo /diagnostics
```

### Test Motor Communication

```bash
# Check joint states from motor manager
ros2 topic echo /motor_manager/joint_states --once

# Run servo connectivity test
ros2 launch llmy_servo_manager ping_test.launch.py
```

### Verify Sensor Data

```bash
# Camera stream (if enabled)
ros2 topic echo /camera/color/image_raw --once

# IMU data (if enabled)
ros2 topic echo /imu/fused --once

# LIDAR scan (if enabled)
ros2 topic echo /scan --once
```

### Test Manual Control

With Xbox controller connected and teleop running:
1. Gently move the right stick → base should move
2. Move the left stick → arm joints 1 & 2 should respond
3. Press D-pad → camera should pan/tilt

---

## Troubleshooting

### Controllers Not Loading

**Symptom:** `ros2 control list_controllers` shows controllers as `unconfigured` or `inactive`

**Solutions:**
```bash
# Check hardware interface connection
ros2 topic echo /motor_manager/joint_states --once

# Manually load controllers
ros2 control load_controller arm_controller
ros2 control configure_controller arm_controller
ros2 control switch_controllers --activate arm_controller
```

### Servo Communication Errors

**Symptom:** Timeout errors or `Failed to communicate with servo ID X`

**Solutions:**
1. Verify servo IDs match configuration file
2. Check baud rate: `servo_baud:=1000000` (common values: 115200, 1000000)
3. Test individual servos with ping test
4. Check physical connections and power supply

### Camera Not Detected

**Symptom:** No camera topics appearing

**Solutions:**
```bash
# List USB devices
lsusb

# Test RealSense directly
realsense-viewer

# Check launch parameters
ros2 launch llmy_camera camera.launch.py --show-args
```

### Xbox Controller Not Responding

**Symptom:** Robot doesn't move with controller input

**Solutions:**
```bash
# Verify controller is detected
ls /dev/input/js*

# Test controller input
jstest /dev/input/js0

# Check teleop node is publishing
ros2 topic echo /cmd_vel
```

---

## Next Steps

### For Developers

- **Explore Packages:** Read the [detailed package documentation](packages.md)
- **Understand Architecture:** Review the system architecture in the [main README](../README.md#-architecture)
- **Customize Configuration:** Edit YAML files in `ros/src/*/config/`
- **Build Custom Modules:** Create new ROS2 packages in `ros/src/`

### Community & Support

- **Issues:** Report bugs at [github.com/cristidragomir97/llmy/issues](https://github.com/cristidragomir97/llmy/issues)
- **Discussions:** Join conversations in GitHub Discussions
- **Documentation:** Contribute improvements via pull requests
---

**You're ready to start experimenting with LLMy!**

For hardware assembly details, see [Assembly Guide](assembly.md). For BOM and sourcing, check [BOM Documentation](bom.md).

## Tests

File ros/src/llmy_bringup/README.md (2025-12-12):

# llmy_bringup

The LLMy Bringup package provides modular launch files that coordinate all LLMy subsystems to bring up the complete robot. The system is organized into three main subsystems for flexible deployment and debugging.

## Modular Architecture

The bringup system is organized into three main categories:

### 1. **Sensors** (`sensors.launch.py`)
- **Cameras**: RealSense RGB-D head camera and USB wrist camera
- **IMU**: Orientation and motion sensing
- **RPLidar**: 2D laser scanner (optional)

### 2. **Motion** (`motion.launch.py`) 
- **Servo Manager**: Low-level motor control via serial communication
- **ROS2 Control Stack**: Robot state publisher, controller manager, and spawners
- **Teleop**: Xbox controller interface
- **Command Velocity Multiplexing**: twist_mux for multiple control sources

### 3. **Communication** (`communication.launch.py`)
- **Rosbridge Server**: WebSocket interface for web applications
- **Rosboard**: Web-based dashboard for monitoring and visualization
- **Image Compression**: Bandwidth optimization for camera feeds
- **Depth-to-Scan**: Convert depth images to laser scan format

## Launch Files

### `bringup_robot.launch.py` (Main Launcher)

Coordinates all three subsystems with high-level enable/disable flags.

| Argument | Default | Description |
|---|---|---|
| `use_sensors` | `true` | Enable all sensor systems |
| `use_motion` | `true` | Enable motion and control systems |
| `use_communication` | `true` | Enable communication and web interfaces |

### `sensors.launch.py`

| Argument | Default | Description |
|---|---|---|
| `use_camera` | `true` | Enable camera system (RealSense + wrist cam) |
| `use_imu` | `true` | Enable IMU sensor |
| `use_rplidar` | `false` | Enable RPLidar C1 |

### `motion.launch.py`

| Argument | Default | Description |
|---|---|---|
| `use_base_systems` | `true` | Enable servo manager (motor control) |
| `use_control_stack` | `true` | Enable robot state publisher and controllers |
| `use_xbox` | `true` | Enable Xbox controller teleoperation |
| `servo_port` | `/dev/ttyTHS1` | Serial port for servo communication |
| `servo_baud` | `1000000` | Baudrate for servo communication |

### `communication.launch.py`

| Argument | Default | Description |
|---|---|---|
| `use_rosbridge` | `true` | Enable rosbridge server for web interfaces |
| `use_rosboard` | `true` | Enable rosboard web dashboard |
| `use_image_compression` | `true` | Enable image compression and depth-to-scan |

## Usage Examples

### Full System Startup

```bash
# Launch complete robot with all systems
ros2 launch llmy_bringup bringup_robot.launch.py
```

### Modular System Startup

```bash
# Launch only sensors (cameras, IMU, optional LiDAR)
ros2 launch llmy_bringup sensors.launch.py

# Launch only motion systems (servos, control, teleop)
ros2 launch llmy_control motion.launch.py

# Launch only communication (web interfaces, compression)
ros2 launch llmy_bringup communication.launch.py
```

### Custom Configurations

```bash
# Launch without communication systems
ros2 launch llmy_bringup bringup_robot.launch.py use_communication:=false

# Launch with RPLidar enabled
ros2 launch llmy_bringup sensors.launch.py use_rplidar:=true

# Launch motion without Xbox controller
ros2 launch llmy_control motion.launch.py use_xbox:=false

# Launch sensors without cameras (IMU only)
ros2 launch llmy_bringup sensors.launch.py use_camera:=false

# Launch with custom serial port
ros2 launch llmy_control motion.launch.py servo_port:=/dev/ttyUSB0
```

### Development Scenarios

```bash
# Sensors + Communication (no motion for safety)
ros2 launch llmy_bringup bringup_robot.launch.py use_motion:=false

# Motion only (for control testing)
ros2 launch llmy_control motion.launch.py

# Full sensor suite with LiDAR
ros2 launch llmy_bringup sensors.launch.py use_rplidar:=true

# Communication with image compression disabled
ros2 launch llmy_bringup communication.launch.py use_image_compression:=false
```

## Command Velocity Multiplexing

The motion launch file includes a `twist_mux` node that multiplexes command velocity from multiple sources:

| Source | Topic | Priority | Description |
|---|---|---|---|
| Xbox | `/cmd_vel_xbox` | 15 (highest) | Xbox controller input |
| Teleop | `/cmd_vel_teleop` | 10 | Manual teleoperation interface |
| Nav | `/cmd_vel_nav` | 5 (lowest) | Navigation stack commands |

All sources are multiplexed to `/omnidirectional_controller/cmd_vel_unstamped` with a 0.5 second timeout.

## Web Interfaces

### Rosboard Dashboard
Access the web dashboard at: `http://localhost:8888`

Features:
- Topic visualization and monitoring
- TF tree viewer
- Live camera feeds
- Service/action inspection
- Parameter configuration

### Rosbridge WebSocket
WebSocket server available at: `ws://localhost:9090`

Enables:
- Web application integration
- Remote monitoring and control
- Real-time data streaming

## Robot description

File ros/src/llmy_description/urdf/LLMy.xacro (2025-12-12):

<?xml version="1.0" ?>
<robot name="LLMy" xmlns:xacro="http://www.ros.org/wiki/xacro">

<xacro:include filename="$(find llmy_description)/urdf/materials.xacro" />
<xacro:include filename="$(find llmy_description)/urdf/LLMy.ros2control" />
<xacro:include filename="$(find llmy_description)/urdf/LLMy.gazebo" />

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
<link name="base_footprint">
</link>

<joint name="base_footprint_joint" type="fixed">
  <parent link="base_footprint"/>
  <child link="base_link"/>
  <origin xyz="0 0 0.015" rpy="0 0 0"/>
</joint>

<link name="base_link">
  <inertial>
    <origin xyz="0.004519913792465928 -1.0204794018520147e-06 0.01628038702095824" rpy="0 0 0"/>
    <mass value="3.733272611066977"/>
    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
  </inertial>
  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
</link>

<link name="arm_base_rotation_link_1">
  <inertial>
    <origin xyz="0.03155604665958371 -0.0002715797504647982 -0.009540113984797205" rpy="0 0 0"/>
    <mass value="0.5385469320676795"/>
    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
  </inertial>
  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
</link>

<link name="arm_base_rotation_link_cover_1">
  <inertial>
    <origin xyz="-0.00949405096701067 0.02324978306162088 -0.0026578741727789207" rpy="0 0 0"/>
    <mass value="0.10853073755546007"/>
    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
  </inertial>
  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
</link>

<link name="arm_shoulder_servo_1">
  <inertial>
    <origin xyz="-0.010249819744280048 -0.016027075057897334 0.019999363228350303" rpy="0 0 0"/>
    <mass value="0.2843033831904074"/>
    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
  </inertial>
  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
</link>

<link name="arm_shoulder_link_1">
  <inertial>
    <origin xyz="-0.052733325697050415 0.019699516785405227 0.024187169163720004" rpy="0 0 0"/>
    <mass value="0.9906249126045027"/>
    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
  </inertial>
  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
</link>

<link name="arm_elbow_link_1">
  <inertial>
    <origin xyz="0.06004007507688957 -0.015214887326993196 0.015943523421851402" rpy="0 0 0"/>
    <mass value="0.8772447501056027"/>
    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
  </inertial>
  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
</link>

<link name="arm_wrist_tilt_servo_1">
  <inertial>
    <origin xyz="0.015287230028536491 0.0160270532478079 0.01647172547314743" rpy="0 0 0"/>
    <mass value="0.2843033831904074"/>
    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
  </inertial>
  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
</link>

<link name="arm_wrist_link_1">
  <inertial>
    <origin xyz="0.011372175899756587 -0.016809794205069263 -0.023803070901329437" rpy="0 0 0"/>
    <mass value="0.2392168278135931"/>
    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
  </inertial>
  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
</link>

<link name="arm_wrist_roll_servo_1">
  <inertial>
    <origin xyz="0.0025984806254740755 -0.015998318175915224 0.018408192115497823" rpy="0 0 0"/>
    <mass value="0.2799142523131049"/>
    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
  </inertial>
  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
</link>

<link name="arm_gripper_1">
  <inertial>
    <origin xyz="0.01141346056132983 -0.01371516137501054 -0.027022930132201528" rpy="0 0 0"/>
    <mass value="0.44698022927880193"/>
    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
  </inertial>
  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
</link>

<link name="arm_gripper_servo_1">
  <inertial>
    <origin xyz="-0.009135471818643631 0.020789302478152534 -0.015692036479927257" rpy="0 0 0"/>
    <mass value="0.2843033831904074"/>
    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
  </inertial>
  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
</link>

<link name="arm_jaw_1">
  <inertial>
    <origin xyz="0.03164807716776416 -0.003660545328676006 -0.018535273594172272" rpy="0 0 0"/>
    <mass value="0.1586808414280307"/>
    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
  </inertial>
  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
</link>

<link name="arm_elbow_servo_1">
  <inertial>
    <origin xyz="-0.03862845468723155 0.15800905991887132 0.06347054327112799" rpy="0 0 0"/>
    <mass value="0.2843033831904074"/>
    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
  </inertial>
  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
</link>

<link name="FR_wheel_1">
  <inertial>
    <origin xyz="-1.3628486138228535e-07 -0.012516648256376106 3.887474835321397e-07" rpy="0 0 0"/>
    <mass value="0.37145856818861533"/>
    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
  </inertial>
  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
</link>

<link name="BR_wheel_1">
  <inertial>
    <origin xyz="-2.2824945711263922e-08 -0.012516628578434372 -1.5802193546743393e-09" rpy="0 0 0"/>
    <mass value="0.37145856818861533"/>
    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
  </inertial>
  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
</link>

<link name="FL_wheel_1">
  <inertial>
    <origin xyz="-1.1477162391304585e-07 0.012516628316043305 3.8872548958901465e-07" rpy="0 0 0"/>
    <mass value="0.3714585647594021"/>
    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
  </inertial>
  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
</link>

<link name="BL_wheel_1">
  <inertial>
    <origin xyz="-1.9875394001445112e-07 0.012516647328723873 3.8881242268515304e-07" rpy="0 0 0"/>
    <mass value="0.371458582321587"/>
    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
  </inertial>
  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
</link>

<link name="baseus_pack_v1_1">
  <inertial>
    <origin xyz="-6.196697373006544e-08 -0.07749999833182192 -0.02250000000000121" rpy="0 0 0"/>
    <mass value="2.7975020361255445"/>
    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
  </inertial>
  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
</link>

<link name="FR_motor_1">
  <inertial>
    <origin xyz="-0.010250129858487292 -0.01615305507844378 -0.019698116587999626" rpy="0 0 0"/>
    <mass value="0.2777820135235829"/>
    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
  </inertial>
  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
</link>

<link name="FL_motor_1">
  <inertial>
    <origin xyz="-0.010250114394607795 0.016153035755998343 -0.019698116587999796" rpy="0 0 0"/>
    <mass value="0.2777820135235829"/>
    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
  </inertial>
  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
</link>

<link name="BL_motor_1">
  <inertial>
    <origin xyz="-0.010250205022044614 0.016153054722989654 -0.019698116588000116" rpy="0 0 0"/>
    <mass value="0.2777820135235829"/>
    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
  </inertial>
  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
</link>

<link name="left_baseus_mount_v1_1">
  <inertial>
    <origin xyz="0.02999994222597873 -0.0023724721267765897 0.023155870997940288" rpy="0 0 0"/>
    <mass value="0.060119830422065"/>
    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
  </inertial>
  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
</link>

<link name="right_baseus_mount_v1_1">
  <inertial>
    <origin xyz="-0.030000074735776126 0.0016153230561984089 0.02249999999999538" rpy="0 0 0"/>
    <mass value="0.08330068022697495"/>
    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
  </inertial>
  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
</link>

<link name="arm_base_rotation_servo_1">
  <inertial>
    <origin xyz="0.019999207811031955 -0.010250007796807441 0.016027400589857632" rpy="0 0 0"/>
    <mass value="0.2843033831904074"/>
    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
  </inertial>
  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
</link>

<link name="base_servo_cover_1">
  <inertial>
    <origin xyz="0.016236786310895465 -0.017449425024270774 0.002612690409162552" rpy="0 0 0"/>
    <mass value="0.18685394642734598"/>
    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
  </inertial>
  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
</link>

<link name="first_floor_v1_1">
  <inertial>
    <origin xyz="0.09433361318248408 -0.07999974548637985 0.0024999983437693635" rpy="0 0 0"/>
    <mass value="1.4859247887314582"/>
    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
  </inertial>
  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
</link>

<link name="capache_v1_1">
  <inertial>
    <origin xyz="0.05981502850767505 -0.08003385023448932 0.1259729417973693" rpy="0 0 0"/>
    <mass value="2.0039722834574425"/>
    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
  </inertial>
  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
</link>

<link name="lidar_1">
  <inertial>
    <origin xyz="-0.02141654572031136 -0.02159454290804581 0.01401842877373849" rpy="0 0 0"/>
    <mass value="0.25367500028622497"/>
    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
  </inertial>
  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
</link>

<link name="senzori_v1_1">
  <inertial>
    <origin xyz="-0.04845875426448515 -0.03998122021368317 0.017931236824216906" rpy="0 0 0"/>
    <mass value="0.2092881828260779"/>
    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
  </inertial>
  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
</link>

<link name="pan_servo__1__1">
  <inertial>
    <origin xyz="-0.016199517891891585 0.010249989297431754 -0.01577293673150887" rpy="0 0 0"/>
    <mass value="0.2843033831904074"/>
    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
  </inertial>
  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
</link>

<link name="tilt_servo_1">
  <inertial>
    <origin xyz="0.01999853723453275 0.01602705422890851 -0.01025000166298845" rpy="0 0 0"/>
    <mass value="0.2843033831904074"/>
    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
  </inertial>
  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
</link>

<link name="camera_plm_v1_1">
  <inertial>
    <origin xyz="-0.021275784258536268 -5.605186459870737e-05 0.014340861715288394" rpy="0 0 0"/>
    <mass value="0.20127872909836297"/>
    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
  </inertial>
  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
</link>

<link name="orin_1">
  <inertial>
    <origin xyz="-0.02998102548537552 0.046402780901215364 0.010403846181521084" rpy="0 0 0"/>
    <mass value="0.4488469641841115"/>
    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
  </inertial>
  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
</link>

<link name="camera_mount_v1_1">
  <inertial>
    <origin xyz="0.12646057810511868 -0.24874307918263064 0.0011981974946090879" rpy="0 0 0"/>
    <mass value="0.14731394162641492"/>
    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
  </inertial>
  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
</link>

<link name="head_camera_1">
  <inertial>
    <origin xyz="0.01244984712621948 -0.021387641747534183 -2.7893140952250928e-05" rpy="0 0 0"/>
    <mass value="0.35928853728306875"/>
    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
  </inertial>
  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
</link>
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

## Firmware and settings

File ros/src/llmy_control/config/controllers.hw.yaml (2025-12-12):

# Controllers for LLMy hardware
controller_manager:
  ros__parameters:
    update_rate: 50  # Hz
    use_sim_time: false

    joint_state_broadcaster:
      type: joint_state_broadcaster/JointStateBroadcaster

    diff_drive_controller:
      type: diff_drive_controller/DiffDriveController

    arm_controller:
      type: position_controllers/JointGroupPositionController

    head_controller:
      type: position_controllers/JointGroupPositionController

arm_controller:
  ros__parameters:
    joints: ["1","2","3","4","5","6"]

    command_interfaces:
      - position

    state_interfaces:
      - position

    open_loop_control: true

head_controller:
  ros__parameters:
    joints: ["pan", "tilt"]

    command_interfaces:
      - position

    state_interfaces:
      - position

    open_loop_control: true

diff_drive_controller:
  ros__parameters:
    # Wheel joints (right side and left side)
    left_wheel_names: ['front_left_wheel_joint', 'back_left_wheel_joint']
    right_wheel_names: ['front_right_wheel_joint', 'back_right_wheel_joint']

    # Robot geometry
    wheel_separation: 0.176  # Distance between left and right wheels (m)
    wheel_radius: 0.025      # Wheel radius (m)

    # Wheel separation multiplier for calibration
    wheel_separation_multiplier: 1.0

    # Frames
    odom_frame_id: odom
    base_frame_id: base_footprint
    pose_covariance_diagonal: [0.001, 0.001, 0.001, 0.001, 0.001, 0.01]
    twist_covariance_diagonal: [0.001, 0.001, 0.001, 0.001, 0.001, 0.01]

    # TF publishing
    enable_odom_tf: true
    publish_rate: 50.0

    # Command timeout
    cmd_vel_timeout: 0.5

    # Velocity limits
    linear.x.has_velocity_limits: true
    linear.x.max_velocity: 1.0
    linear.x.min_velocity: -1.0
    linear.x.has_acceleration_limits: true
    linear.x.max_acceleration: 2.0

    angular.z.has_velocity_limits: true
    angular.z.max_velocity: 2.0
    angular.z.min_velocity: -2.0
    angular.z.has_acceleration_limits: true
    angular.z.max_acceleration: 3.0

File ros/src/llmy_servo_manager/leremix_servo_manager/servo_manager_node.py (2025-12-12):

#!/usr/bin/env python3
"""
Python-based Servo Manager Node for LLMy Robot
Uses ST3215 library with improved braking logic to prevent power spikes
"""

import rclpy
from rclpy.node import Node
from rclpy.qos import QoSProfile, ReliabilityPolicy, HistoryPolicy
from std_msgs.msg import Float64MultiArray

from .config import ServoManagerConfig
from .motor_manager import MotorManager
from .brake_system import BrakeSystem
from .command_handlers import CommandHandlers

from .telemetry import TelemetrySystem

class ServoManagerNode(Node):
    def __init__(self):
        super().__init__('servo_manager_node_py')
        
        self.get_logger().info("=== LLMy Python Servo Manager Node Starting ===")
        
        # Load configuration
        self.get_logger().info("Loading servo manager configuration...")
        self.config = ServoManagerConfig(self)
        self.config.log_configuration()
        
        # Initialize motor manager
        self.motor_manager = MotorManager(self, self.config.port, self.config.baud)
        
        # Connect to motor bus
        self.get_logger().info("Attempting to connect to FEETECH servo bus...")
        if not self.motor_manager.connect():
            raise RuntimeError("Failed to connect to FEETECH servo bus")
        
        # Test connectivity and initialize motors
        enabled_ids = self.config.get_enabled_motor_ids()
        connected_count = self.motor_manager.test_connectivity(enabled_ids)
        if connected_count > 0:
            self.motor_manager.run_test_sequences(enabled_ids, self.config.loc_ids, 
                                                self.config.arm_ids, self.config.head_ids, 
                                                self.config.loc_enable)
        
        # Add delay between test sequences and initialization to prevent bus congestion
        import time
        time.sleep(0.5)
        
        self._initialize_motors()
        
        # Initialize brake system
        self.brake_system = BrakeSystem(self, self.motor_manager, self.config.brake_method,
                                       self.config.velocity_ramp_time, self.config.brake_acceleration)
        
        # Initialize command handlers
        self.command_handlers = CommandHandlers(self, self.motor_manager, self.config)
        
        # Initialize telemetry system
        self.telemetry = TelemetrySystem(self, self.motor_manager, self.config)
        
        self._setup_ros_communication()
        
        # Publish initial joint states immediately to inform ros2_control of current positions
        self.get_logger().info("Publishing initial joint states for ros2_control awareness...")
        self.telemetry.publish_telemetry()
        import time
        time.sleep(0.1)  # Brief delay to ensure message is published
        self.telemetry.publish_telemetry()  # Publish twice to ensure ros2_control receives it
        
        self._log_startup_summary()
    
    def _initialize_motors(self):
        """Initialize all motor groups"""
        self.get_logger().info("Initializing motor modes and positions...")
        
        if self.config.loc_enable:
            self.motor_manager.initialize_locomotion_motors(self.config.loc_ids, self.config.loc_accel)
        
        if self.config.arm_enable:
            self.motor_manager.initialize_arm_motors(self.config.arm_ids, self.config.arm_accel, self.config.ticks_per_rev)
        
        if self.config.head_enable:
            self.motor_manager.initialize_head_motors(self.config.head_ids, self.config.head_accel, self.config.ticks_per_rev)
        
        self.get_logger().info("Motor initialization complete!")
    
    def _setup_ros_communication(self):
        """Setup ROS subscribers, publishers and timers"""
        self.get_logger().info("Setting up ROS2 communication...")
        
        # Create QoS profile matching C++ version
        cmd_qos = QoSProfile(
            history=HistoryPolicy.KEEP_LAST,
            depth=10,
            reliability=ReliabilityPolicy.BEST_EFFORT
        )
        
        # Create subscribers
        self.get_logger().info("Creating command subscribers:")
        self.base_cmd_sub = self.create_subscription(
            Float64MultiArray,
            "/motor_manager/base_cmd",
            self.command_handlers.handle_base_command,
            cmd_qos
        )
        self.get_logger().info("  ✅ Base command subscriber: /motor_manager/base_cmd")
        
        self.arm_cmd_sub = self.create_subscription(
            Float64MultiArray,
            "/motor_manager/arm_cmd", 
            self.command_handlers.handle_arm_command,
            cmd_qos
        )
        self.get_logger().info("  ✅ Arm command subscriber: /motor_manager/arm_cmd")
        
        self.head_cmd_sub = self.create_subscription(
            Float64MultiArray,
            "/motor_manager/head_cmd",
            self.command_handlers.handle_head_command,
            cmd_qos
        )
        self.get_logger().info("  ✅ Head command subscriber: /motor_manager/head_cmd")
        
        # Create timer for telemetry
        timer_period = 1.0 / self.config.telemetry_rate
        self.timer = self.create_timer(timer_period, self.telemetry.publish_telemetry)
        self.get_logger().info(f"  ✅ Telemetry timer started at {self.config.telemetry_rate} Hz")
    
    def _log_startup_summary(self):
        """Log startup summary information"""
        self.get_logger().info("🚀 === Python Servo Manager Node Successfully Started ===")
        self.get_logger().info("📊 System Summary:")
        self.get_logger().info(f"  🏃 Locomotion motors: {len(self.config.loc_ids)} ({'ENABLED' if self.config.loc_enable else 'DISABLED'})")
        self.get_logger().info(f"  🦾 Arm motors: {len(self.config.arm_ids)} ({'ENABLED' if self.config.arm_enable else 'DISABLED'})")
        self.get_logger().info(f"  🗣️  Head motors: {len(self.config.head_ids)} ({'ENABLED' if self.config.head_enable else 'DISABLED'})")
        
        enabled_count, total_count = self.config.get_motor_counts()
        self.get_logger().info(f"  📡 Total motors enabled: {enabled_count}/{total_count}")
        self.get_logger().info("----------------------------------")
        self.get_logger().info("Ready to receive motor commands and publish telemetry!")

def main(args=None):
    rclpy.init(args=args)

    try:
        node = ServoManagerNode()
        rclpy.spin(node)
    except KeyboardInterrupt:
        pass
    except Exception as e:
        print(f"Error during servo manager initialization: {e}")
    finally:
        if rclpy.ok():
            rclpy.shutdown()

if __name__ == '__main__':
    main()

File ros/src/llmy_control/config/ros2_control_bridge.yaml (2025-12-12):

# ros2_control hardware config that loads the ROS2ControlBridge plugin
ros2_control:
  ros__parameters:
    hardware:
      plugin: llmy_control_plugin/ROS2ControlBridge

      # Topics for communication with servo manager
      base_cmd_topic: /motor_manager/base_cmd
      arm_cmd_topic: /motor_manager/arm_cmd
      head_cmd_topic: /motor_manager/head_cmd
      state_topic: /motor_manager/joint_states

      # optional
      publish_if_unchanged: true

    joints:
      # Base joints — velocity command, position+velocity states
      - name: front_right_wheel_joint
        command_interfaces: [velocity]
        state_interfaces: [position, velocity]
      - name: back_right_wheel_joint
        command_interfaces: [velocity]
        state_interfaces: [position, velocity]
      - name: front_left_wheel_joint
        command_interfaces: [velocity]
        state_interfaces: [position, velocity]
      - name: back_left_wheel_joint
        command_interfaces: [velocity]
        state_interfaces: [position, velocity]

      # Arm joints — position command, position state
      - name: "1"
        command_interfaces: [position]
        state_interfaces: [position]
      - name: "2"
        command_interfaces: [position]
        state_interfaces: [position]
      - name: "3"
        command_interfaces: [position]
        state_interfaces: [position]
      - name: "4"
        command_interfaces: [position]
        state_interfaces: [position]
      - name: "5"
        command_interfaces: [position]
        state_interfaces: [position]
      - name: "6"
        command_interfaces: [position]
        state_interfaces: [position]

      # Head joints — position command, position state
      - name: tilt
        command_interfaces: [position]
        state_interfaces: [position]
      - name: pan
        command_interfaces: [position]
        state_interfaces: [position]

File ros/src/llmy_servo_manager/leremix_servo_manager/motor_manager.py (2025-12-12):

#!/usr/bin/env python3
"""
Motor Manager for LLMy Robot
Handles low-level motor communication and control using ST3215 library
"""

import math
import time
from st3215 import ST3215
from rclpy.node import Node


class MotorManager:
    """Manages communication and control of FEETECH servo motors"""
    
    def __init__(self, node: Node, port: str, baud: int = 1000000):
        self.node = node
        self.port = port
        self.baud = baud
        self.motor_manager = None
        self.velocity_mode_initialized = set()
        self.running_motors = {}  # motor_id -> current_speed
        
    def connect(self):
        """Connect to the motor bus"""
        try:
            self.motor_manager = ST3215(self.port)
            self.node.get_logger().info(f"✅ Successfully connected to serial port: {self.port}")
            return True
        except Exception as e:
            self.node.get_logger().error(f"❌ Failed to open serial port: {e}")
            self.node.get_logger().error("Please check:")
            self.node.get_logger().error("  - Serial port exists and has correct permissions")
            self.node.get_logger().error("  - Device is connected and powered on")
            self.node.get_logger().error("  - No other processes are using the port")
            return False
    
    def test_connectivity(self, enabled_ids: list):
        """Test connectivity with enabled motors"""
        self.node.get_logger().info("Testing enabled motor connectivity...")
        
        if not enabled_ids:
            self.node.get_logger().warn("No motor groups enabled - skipping connectivity test")
            return 0
            
        connected_motors = 0
        for motor_id in enabled_ids:
            if self.motor_manager.PingServo(motor_id):
                connected_motors += 1
                self.node.get_logger().info(f"  Motor ID {motor_id}: ✅ ONLINE")
            else:
                self.node.get_logger().warn(f"  Motor ID {motor_id}: ❌ OFFLINE")
                
        self.node.get_logger().info(f"Motor connectivity test complete: {connected_motors}/{len(enabled_ids)} enabled motors online")
        return connected_motors
    
    def run_test_sequences(self, motor_ids: list, loc_ids: list, arm_ids: list, head_ids: list, loc_enable: bool):
        """Run short test sequences to verify motor communication"""
        self.node.get_logger().info("Running motor communication test sequences...")
        
        for motor_id in motor_ids:
            if not self.motor_manager.PingServo(motor_id):
                continue
                
            try:
                self.node.get_logger().info(f"Testing motor {motor_id}...")
                
                # Test 1: Brief spin in velocity mode for locomotion motors
                if motor_id in loc_ids and loc_enable:
                    self.motor_manager.SetMode(motor_id, 1)  # Velocity mode
                    self.motor_manager.StartServo(motor_id)
                    self.motor_manager.Rotate(motor_id, 500)  # Slow spin
                    time.sleep(1.0)
                    self.motor_manager.Rotate(motor_id, 0)
                    # Don't stop servo - it will be reinitialized later
                    self.node.get_logger().info(f"  Motor {motor_id}: Velocity test ✅")
                
                # Test 2: Small position move for arm/head motors
                elif motor_id in arm_ids + head_ids:
                    self.motor_manager.SetMode(motor_id, 0)  # Position mode
                    self.motor_manager.StartServo(motor_id)
                    
                    # Read current position and move slightly
                    current_pos = self.motor_manager.ReadPosition(motor_id)
                    if current_pos is not None:
                        test_pos = current_pos + 100  # Small movement
                        test_pos = max(0, min(4095, test_pos))
                        
                        self.motor_manager.MoveTo(motor_id, test_pos, 500, 200)
                        time.sleep(0.5)
                        self.motor_manager.MoveTo(motor_id, current_pos, 500, 200)
                        self.node.get_logger().info(f"  Motor {motor_id}: Position test ✅")
                    
                time.sleep(0.2)  # Brief pause between motors
                
            except Exception as e:
                self.node.get_logger().warn(f"Test failed for motor {motor_id}: {e}")
                
        self.node.get_logger().info("Motor test sequences complete!")
    
    def initialize_locomotion_motors(self, loc_ids: list, loc_accel: list):
        """Initialize locomotion motors for velocity mode"""
        self.node.get_logger().info("Setting locomotion motors to velocity mode...")
        
        for i, motor_id in enumerate(loc_ids):
            accel = loc_accel[i] if i < len(loc_accel) else 50
            
            try:
                self.motor_manager.SetMode(motor_id, 1)  # Velocity mode
                self.motor_manager.StartServo(motor_id)
                
                self.velocity_mode_initialized.add(motor_id)
                self.running_motors[motor_id] = 0
                self.node.get_logger().info(f"Initialized locomotion motor {motor_id}")
            except Exception as e:
                self.node.get_logger().warn(f"Failed to initialize locomotion motor {motor_id}: {e}")
    
    def initialize_arm_motors(self, arm_ids: list, arm_accel: list, ticks_per_rev: int):
        """Initialize arm motors for position mode - reads current positions and sets holding torque"""
        self.node.get_logger().info("Setting arm motors to position mode...")
        self.node.get_logger().info("🛡️  SAFETY: Reading current arm positions and enabling torque holding")
        
        # Store current positions for safety - no movements during initialization
        self.arm_current_positions = {}
        
        for i, motor_id in enumerate(arm_ids):
            accel = arm_accel[i] if i < len(arm_accel) else 20
            
            try:
                # Set mode and acceleration but don't start servo yet
                self.motor_manager.SetMode(motor_id, 0)
                self.motor_manager.SetAcceleration(motor_id, accel)
                
                # Read current position instead of moving to home
                current_pos_ticks = self.motor_manager.ReadPosition(motor_id)
                if current_pos_ticks is not None:
                    # Convert to radians and degrees for logging
                    servo_center = 2048
                    current_angle_rad = (current_pos_ticks - servo_center) / ticks_per_rev * 2.0 * math.pi
                    current_angle_deg = current_angle_rad * 180.0 / math.pi
                    
                    # Store current position
                    self.arm_current_positions[motor_id] = current_pos_ticks
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

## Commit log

2025-09-09 finally fixed urdf joints
    [LeRemix.xacro, arm_base_1.stl, arm_base_rotation_link_1.stl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]
2025-09-11 added lidar and wrist camera urdf
    [LeRemix.xacro, arm_base_1.stl, arm_base_rotation_link_1.stl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]
2025-09-12 added fixes for simulation
    [LeRemix.xacro, controllers.sim.yaml, gazebo_configs.xacro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]
2025-09-12 patched ros_control for tower
    [LeRemix.xacro, controllers.hw.yaml, controllers.yaml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]
2025-09-12 forgot to add urdf overlay to cmakelists in leremix_control
2025-09-16 slow brakeing is back, but at least we are running straight af
    [LeRemix.hardware.xacro, controllers.base.yaml, controllers.hw.yaml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]
2025-09-17 Update control plugin topics from /esp32/* to /motor_manager/*
    - Change base_cmd_topic from /esp32/base_cmd to /motor_manager/base_cmd
    - Change arm_cmd_topic from /esp32/arm_cmd to /motor_manager/arm_cmd
    - Change head_cmd_topic from /esp32/head_cmd to /motor_manager/head_cmd
    - Change state_topic from /esp32/joint_states to /motor_manager/joint_states
    - Update comment to reflect motor manager bridge instead of micro-ROS
    [ros2_control_esp32_bridge.yaml]
2025-09-18 a fuckton of changes
    [LeRemix.hardware.xacro, controllers.hw.yaml, servo_manager.yaml]
2025-09-22 finally working locomotion
    [servo_manager.yaml]
2025-10-01 improved documentation everywhere
    [LeRemix.hardware.xacro, base_plate.stl, baseus2.stl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]
2025-10-01 added missing parts
    [adafruit_i2c_switch_mount.stl, adafruit_icm_mount.stl, adafruit_usb_pd_mount.stl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]
2025-10-01 fixed tiny bug that made the robot spin after initialisation
    [calibrate_arm.py, motor_manager.py, set_servo_id.py]
2025-10-02 fixed locomotion issue
    [LeRemix.hardware.xacro, servo_manager.yaml]
2025-10-03 fixed all types of motion
    [controllers.hw.yaml, servo_manager.yaml]
2025-10-16 making it more compatible with robocore-cli
    [servo_manager.yaml]
2025-11-19 upgraded to foxy, added slam
    [LeRemix.xacro, controllers.hw.yaml, controllers.sim.yaml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]
2025-11-20 upgraded to gz harmonic
    [gazebo_plugins.xacro]
2025-11-21 updates on harmonic simulation
    [LeRemix.xacro, body_collision.stl, controllers.hw.yaml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]
2025-11-21 deleted models
    [body_collision.stl, d435_holder_combined.stl, front_left_hip_collision.stl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]
2025-12-12 changed to skid drive
    [LeRemix.hardware.xacro, LeRemix.xacro, arm_base_1.stl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]
2025-12-12 source was missing
    [BL_motor_1.stl, BL_wheel_1.stl, BR_motor_1.stl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]
